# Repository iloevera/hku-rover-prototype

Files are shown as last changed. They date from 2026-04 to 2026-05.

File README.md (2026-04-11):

# HKU Martians Prototype Rover

Rudimentary all-in-one Power Distribution Board (PDB) and logic carrier designed for small 6-wheel rovers with a 4-DoF robotic arm.

Untitled design (4)

## 🚀 Key Specifications
- **Dimensions:** 97.0 x 77.4 mm
- **Power Input:** 6S LiPo (22.2V nominal, 25.2V max) via XT60.
- **Power Tree:**
  - **12V @ 30A:** High-current rail for BLDC/DC Main Drive motors. External module attached through XT30 connectors
  - **7.5V @ 5A:** Dedicated HV Servo rail (Optimized for 7.4V nominal servos). External module attached through XT30 connectors
  - **5.1V @ 5A:** On-board stabilized logic power for Pi 5 and peripherals. 3V3 Using Pico's built-in regulator.
- **Processing:**
  - Dual-core architecture: Raspberry Pi 5 (Thinking) + Pi Pico 2 (Doing).
  - High-speed UART communication bridge.
- **Actuation & Sensing:**
  - 6x PWM Encoder inputs.
  - 6x PWM-Controlled DC motor driver headers.
  - 4x High-Torque Servo ports with localized bulk capacitance.
  - Integrated 6S Battery Fuel Gauge (Voltage Divider + ADC).

## 🛠 Hardware Setup
### Battery Monitor Calibration
The internal voltage divider uses a **100kΩ (Top)** and **13.7kΩ (Bottom)** 1% precision resistor set. 
- **Max Input:** 25.2V
- **ADC Output:** ~3.03V
- **Safety Factor:** 10% headroom to prevent Pico ADC overvoltage.

### Communication
The Pi 5 and Pico 2 communicate via UART.
- **Baud Rate:** 115200 (Default)
- **Pinout:** Pi GPIO 14/15 <-> Pico GPIO 0/1.

## ⚠️ Assembly Warnings
1. **Thermal Reliefs:** High-current pads (XT60, Regulators, Motors) have thermal reliefs **DISABLED**. Use a high-power chisel-tip iron and pre-heat the board to 100°C for assembly.
2. **Capacitors:** Ensure C1 & C2 (2000uF) is rated for 50V minimum.
3. **USB Isolation:** Always use a USB isolator when debugging the Pi/Pico while the main battery is connected to prevent back-powering your PC.

## 📜 License
This project is released under GNU General Public License v3.0. Designed by **Ilo Japar / HKU ROVER Team**.

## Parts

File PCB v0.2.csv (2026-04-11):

Reference | Qty | Value | Taobao
C1,C2 | 2 | 1000u 50V (E) | https://item.taobao.com/item.htm?id=522579424493&skuId=4292850932858
C3,C4,C7 | 3 | 0.1u 50V 1206 (C) | https://item.taobao.com/item.htm?id=522554243102
C5 | 1 | 470u 50V (E) | https://item.taobao.com/item.htm?id=565000050337&skuId=4839680676732
C6,C8,C9,C10,C11 | 5 | 100u 50V (E) | https://item.taobao.com/item.htm?id=564996742055&skuId=5731925888317
D1 | 1 | 14.7V | https://item.taobao.com/item.htm?id=695101953366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
D2 | 1 | 3.3V | https://item.taobao.com/item.htm?id=697021351088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
D3 | 1 | SK1010C | https://item.taobao.com/item.htm?id=661190438436
D4 | 1 | SMAJ6.0A | https://item.taobao.com/item.htm?id=626801460817
D5,D6,D7,D8 | 4 | Green 0805 | https://item.taobao.com/item.htm?id=522554271548&skuId=5766142345201
F1 | 1 | 30A | https://item.taobao.com/item.htm?id=646550973988&upStreamPrice=131&skuId=5317343647485
F2 | 1 | 5A 1812 | https://detail.tmall.com/item.htm?id=680110340340&xxc=shop&skuId=5053061151671
F3 | 1 | 500mA 1206 | https://detail.tmall.com/item.htm?id=671048655631&skuId=4995581658123&xxc=shop
FB1,FB2,FB3 | 3 | BLM21PG220 | https://detail.tmall.com/item.htm?id=733934301476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
J1 | 1 | XT60-M | https://item.taobao.com/item.htm?from=cart&id=635227665423&skuId=4544457080563&upStreamPrice=247
J2 | 1 | Raspberry Pi 5 | https://item.taobao.com/item.htm?id=522576768218&skuId=3150252041904
J3,J5 | 2 | XT30-F | https://item.taobao.com/item.htm?from=cart&id=635227665423&skuId=4544457080563&upStreamPrice=247
J4,J6 | 2 | XT30-M | https://item.taobao.com/item.htm?from=cart&id=635227665423&skuId=4544457080563&upStreamPrice=247
J7,J8,J9,J10,J11,J12 | 6 | Screw 2.54mm 5P | https://item.taobao.com/item.htm?id=642057328277&skuId=4619071856328
J13,J14,J15,J16 | 4 | 2.54mm 3P | https://item.taobao.com/item.htm?id=522579376259&skuId=6139961763384
J17,J18,J19,J20,J21,J22 | 6 | JST-SH 3P | https://item.taobao.com/item.htm?id=616913039189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
Q1 | 1 | NCE1540KA | https://item.taobao.com/item.htm?id=809752933171
R1,R2 | 2 | 100k 0805 1% | https://item.taobao.com/item.htm?id=526088038633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
R3 | 1 | 13.3k 0805 1% | https://item.taobao.com/item.htm?id=526088038633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
R4,R5,R6,R7,R8 | 5 | 470R 0805 | https://item.taobao.com/item.htm?id=522573121620&skuId=5702455484812
U1 | 1 | 3.2~32V -> 5.1V 5A | https://item.taobao.com/item.htm?id=530479908999

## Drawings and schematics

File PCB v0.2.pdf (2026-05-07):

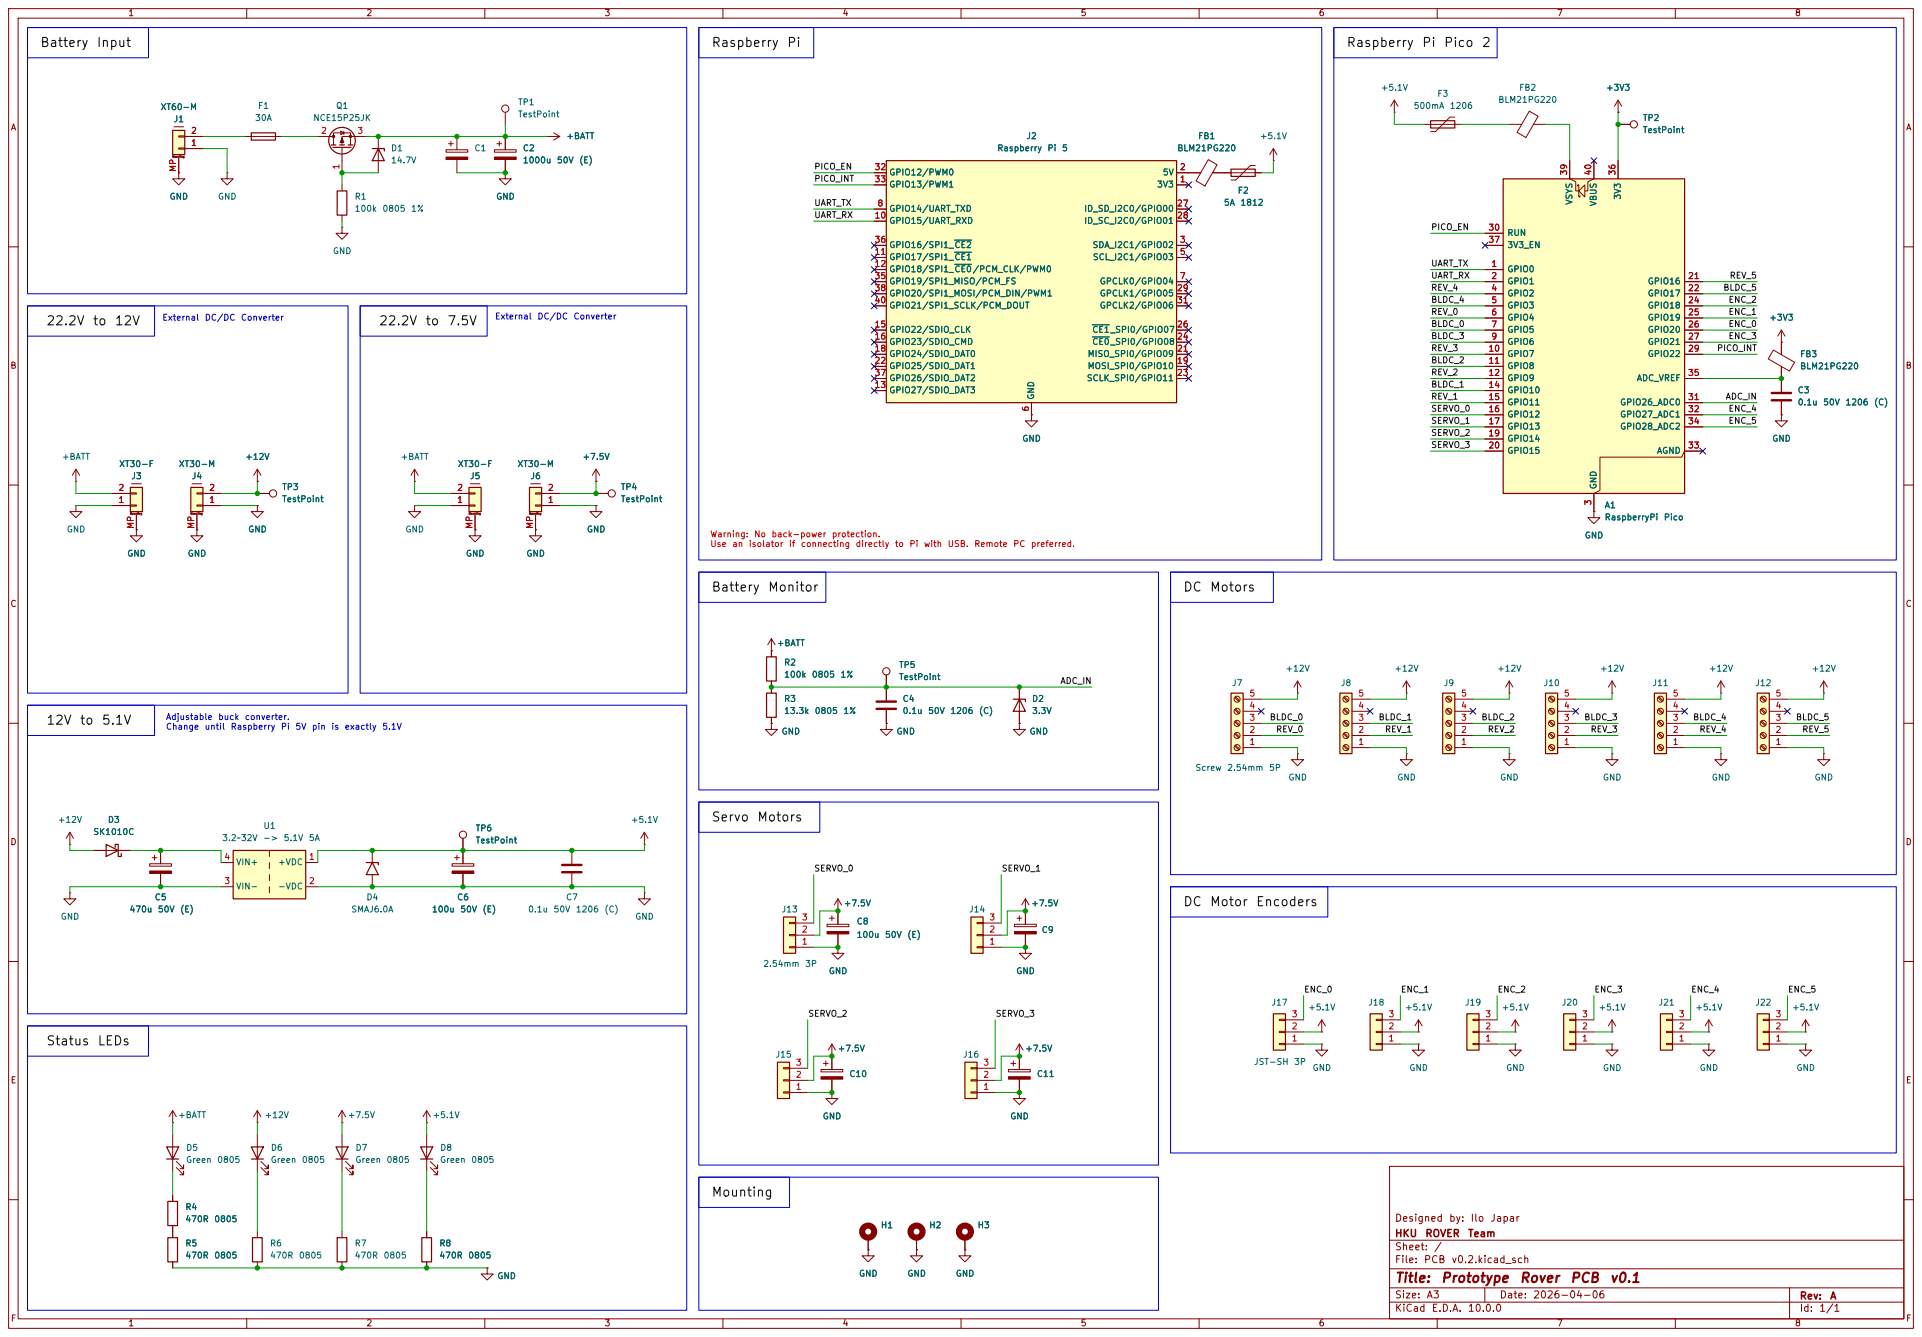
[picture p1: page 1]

+BATT
J2 Raspberry Pi 5 GND +7.5V GND

Use an isolator if connecting directly to Pi with USB. Remote PC preferred.

Adjustable buck converter.
Change until Raspberry Pi 5V pin is exactly 5.1V

Designed by: Ilo Japar
HKU ROVER Team
Sheet: /
File: PCB v0.2.kicad_sch
Title: Prototype Rover PCB v0.1

Size: A3 | Rev: A | F Date: 2026-04-06 KiCad E.D.A. 10.0.0

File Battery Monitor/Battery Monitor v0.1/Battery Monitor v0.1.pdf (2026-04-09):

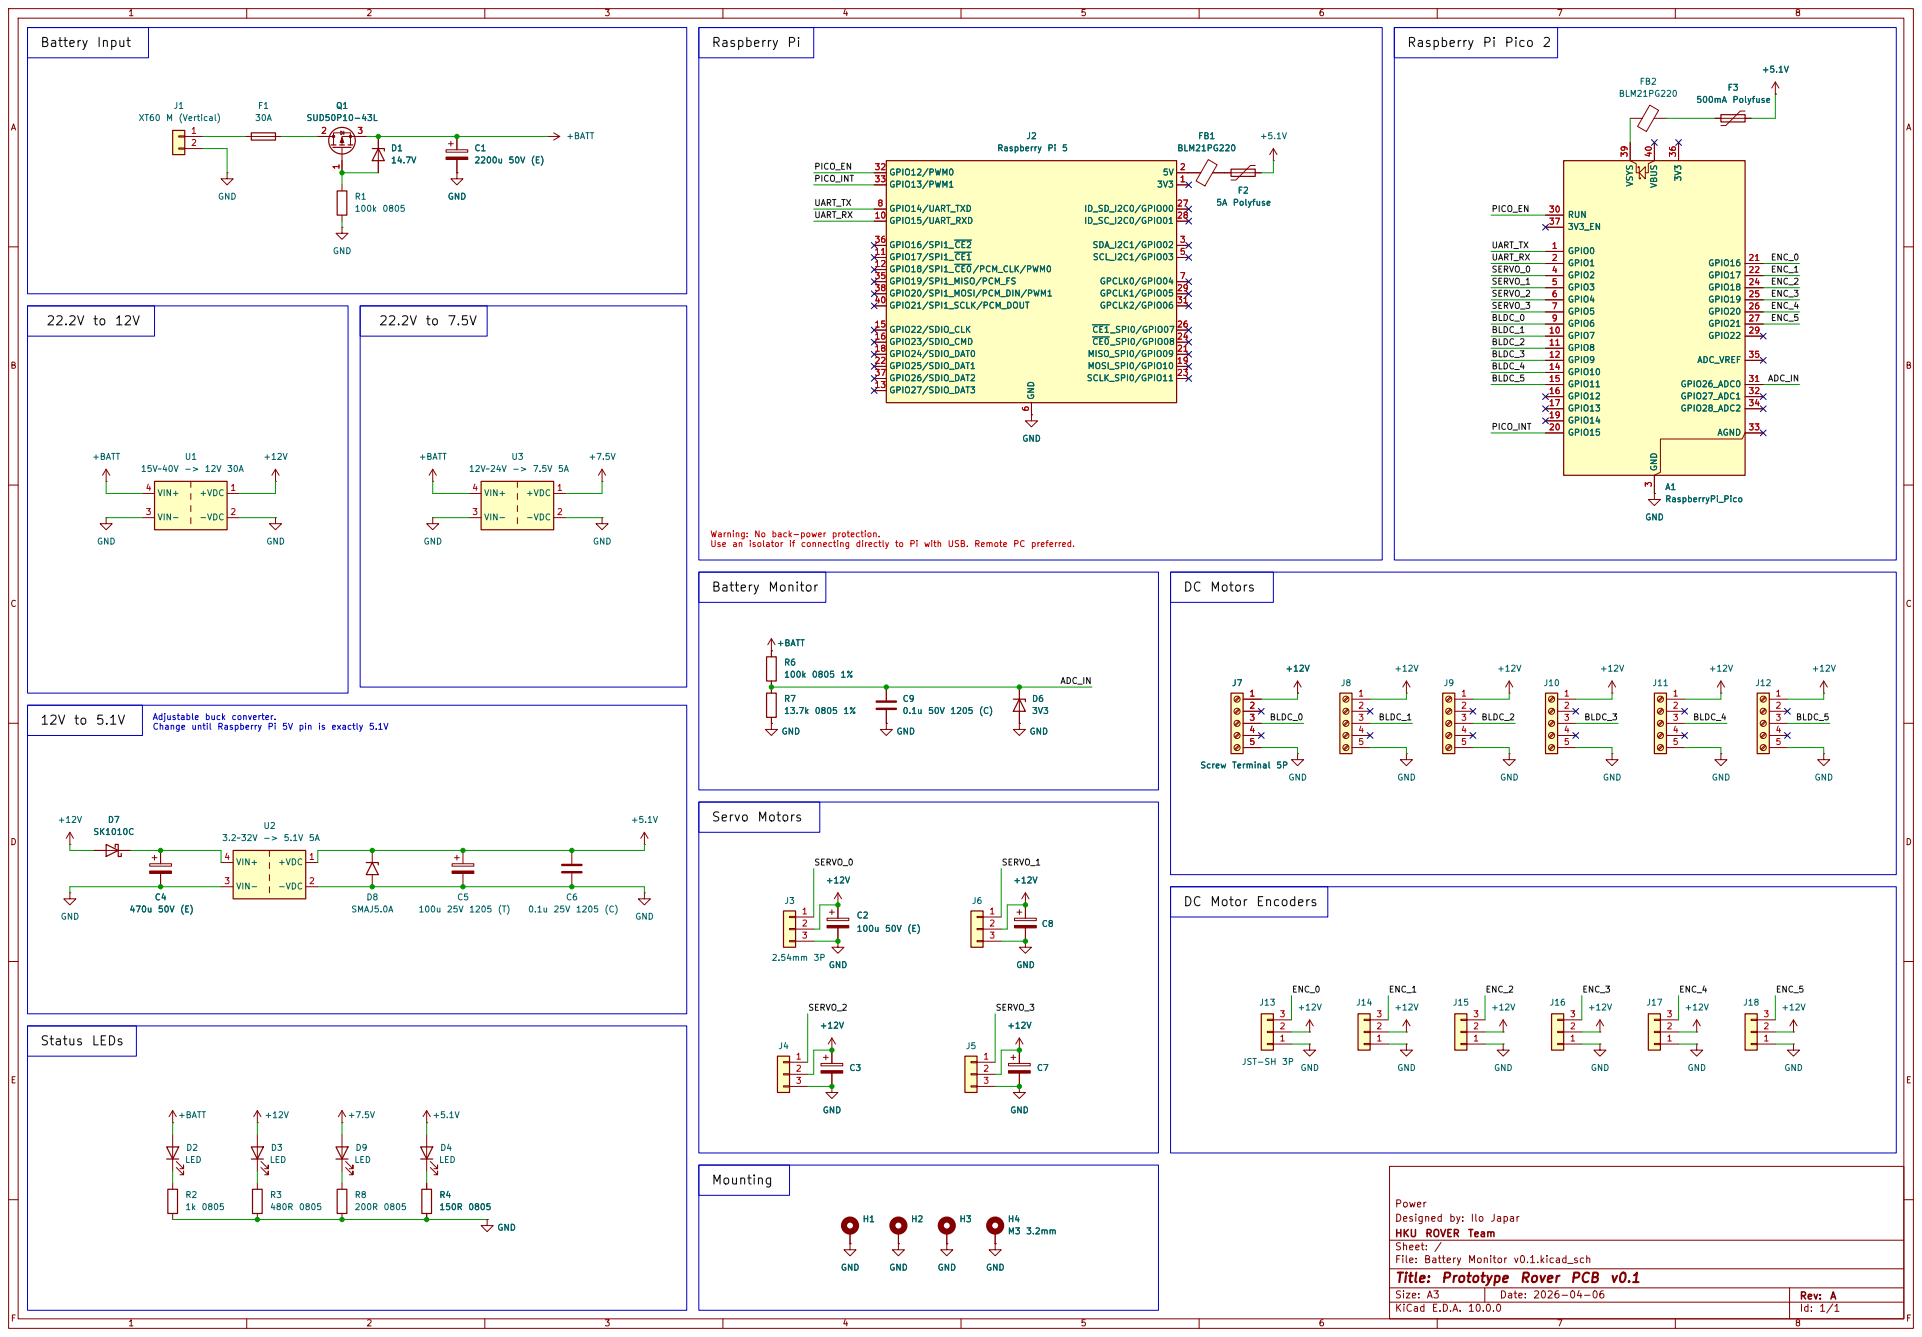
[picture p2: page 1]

Use an isolator if connecting directly to Pi with USB. Remote PC preferred. Q1

Designed by: Ilo Japar Power

HKU ROVER Team
Sheet: /
File: Battery Monitor v0.1.kicad_sch
Title: Prototype Rover PCB v0.1

Size: A3 | Rev: A | F Date: 2026-04-06 KiCad E.D.A. 10.0.0

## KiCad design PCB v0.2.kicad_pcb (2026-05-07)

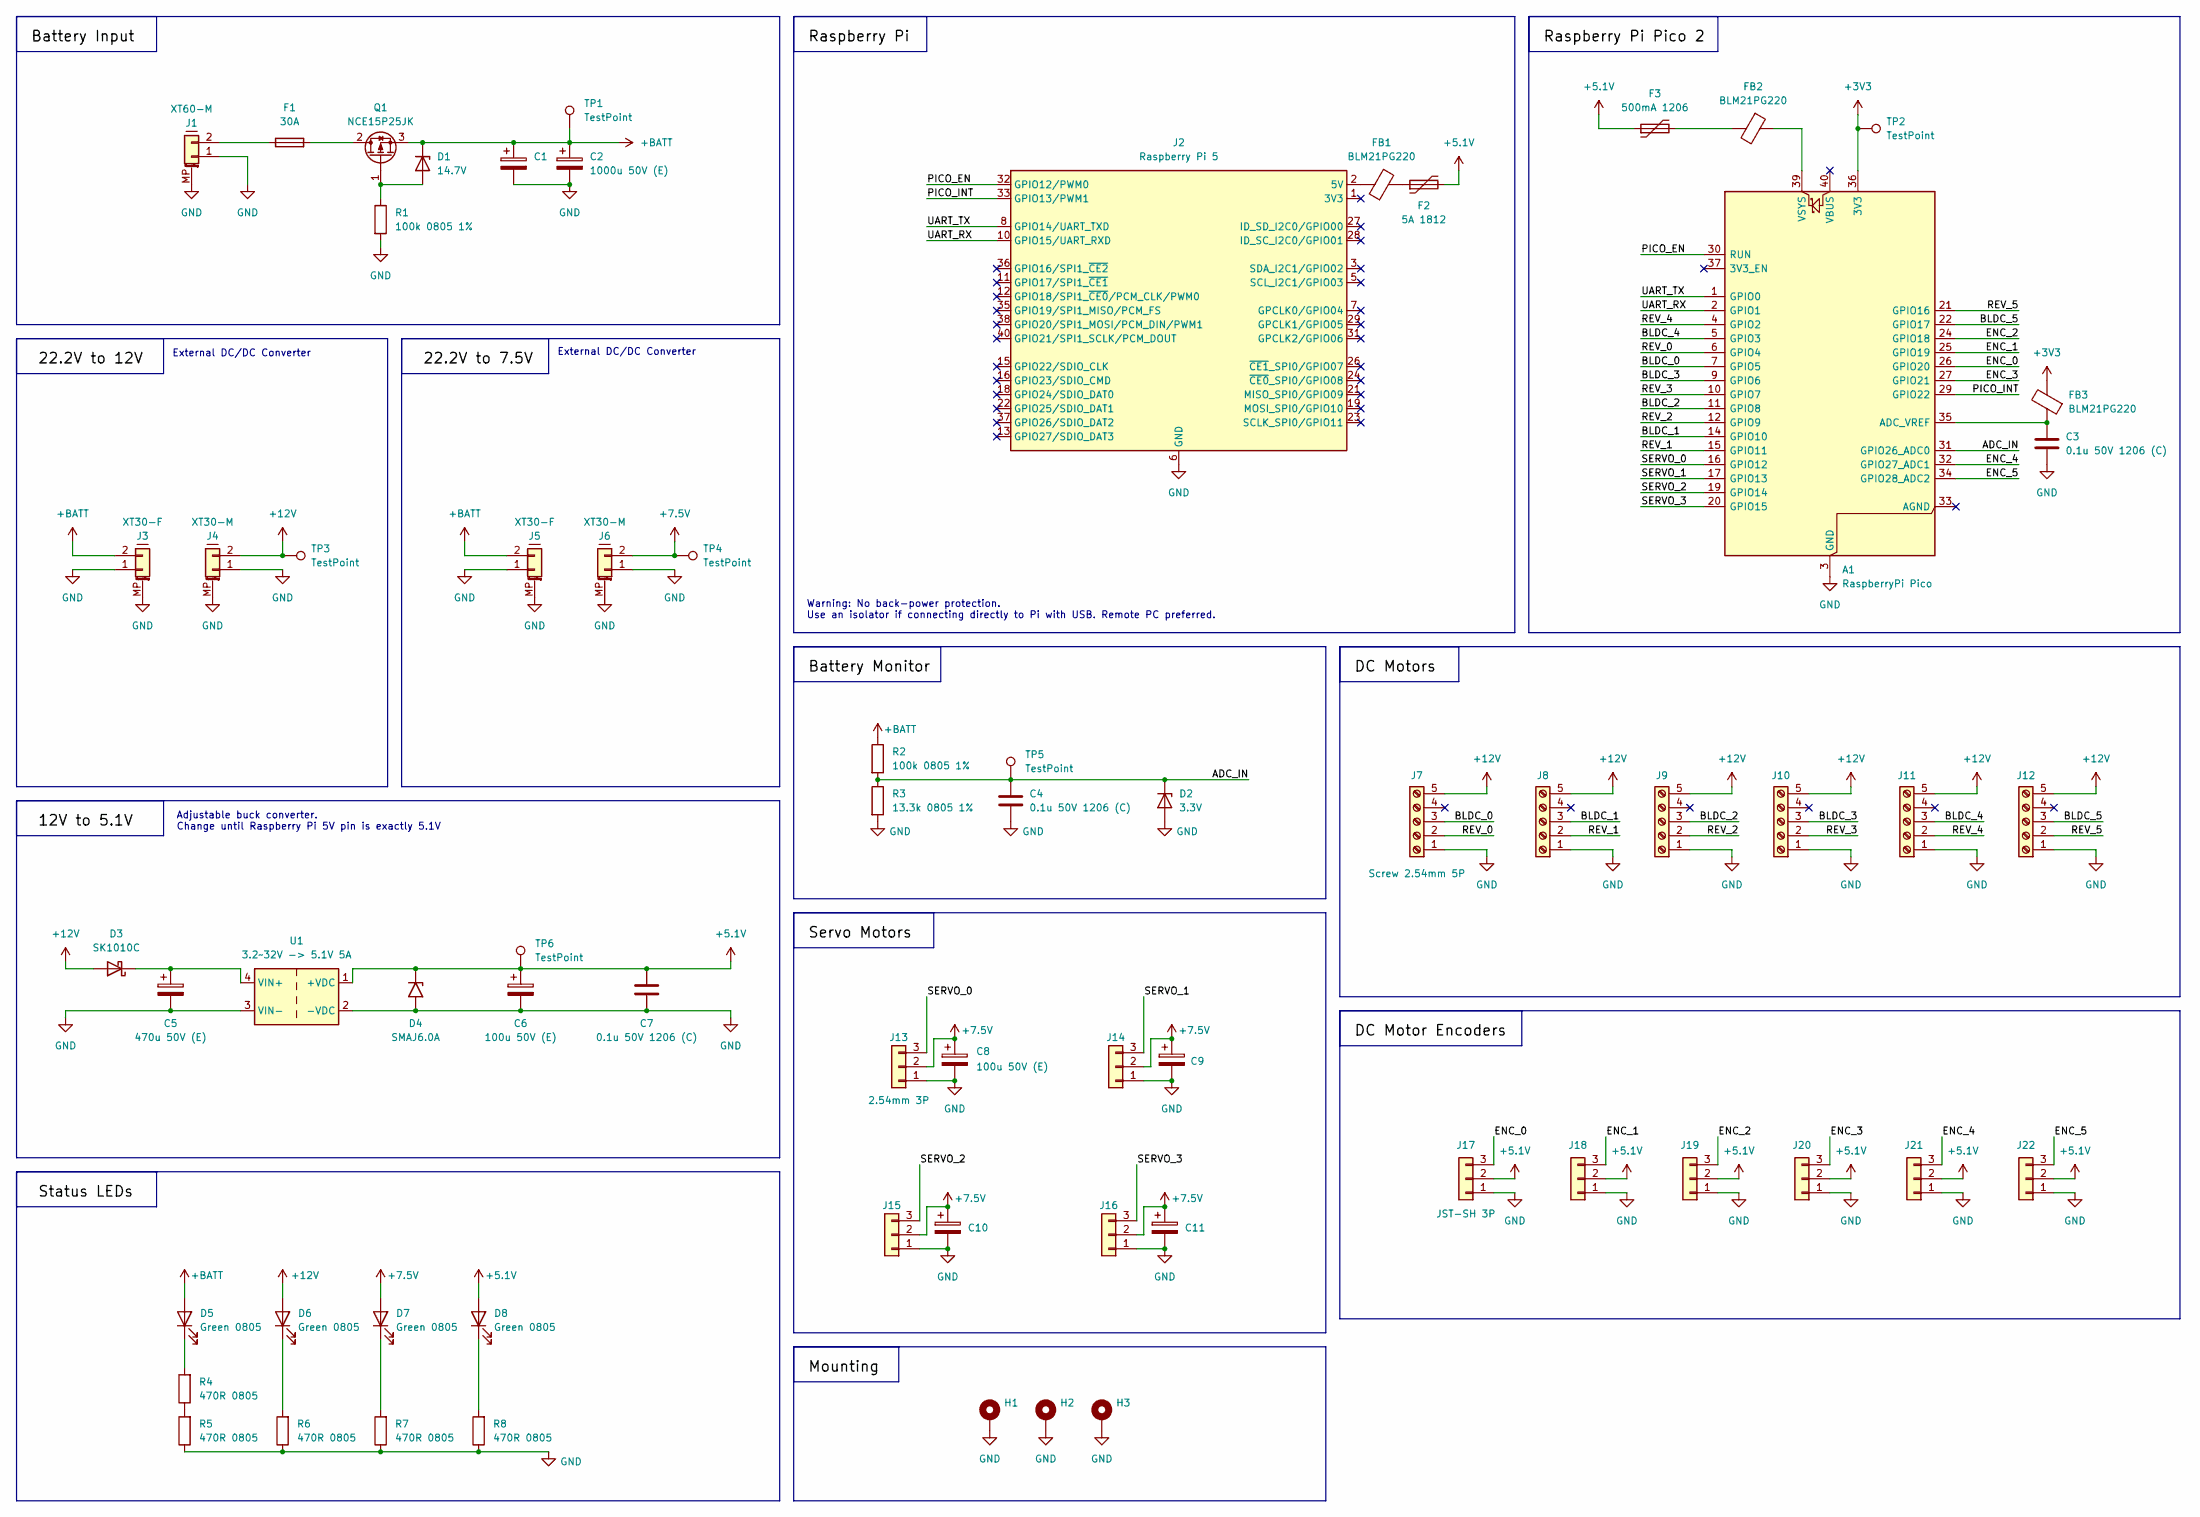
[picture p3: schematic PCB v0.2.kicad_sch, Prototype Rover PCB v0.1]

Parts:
A1: RaspberryPi Pico; RaspberryPi_Pico_SMD_HandSolder
C1, C2: 1000u 50V (E); CP_Radial_D13.0mm_P5.00mm
C3, C4, C7: 0.1u 50V 1206 (C); C_1206_3216Metric_Pad1.33x1.80mm_HandSolder
C5: 470u 50V (E); CP_Radial_D10.0mm_P5.00mm
C6, C8, C9, C10, C11: 100u 50V (E); CP_Radial_D8.0mm_P3.50mm
D1: 14.7V; Nexperia_CFP3_SOD-123W
D2: 3.3V; Nexperia_CFP3_SOD-123W
D3: SK1010C; D_SMC_Handsoldering
D4: SMAJ6.0A; D_SMA
D5, D6, D7, D8: Green 0805; LED_0805_2012Metric_Pad1.15x1.40mm_HandSolder
F1: 30A; FuseHolder_Blade_ATO_Littelfuse_FLR_178.6165
F2: 5A 1812; Fuse_1206_3216Metric
F3: 500mA 1206; Fuse_1206_3216Metric
FB1, FB2, FB3: BLM21PG220; L_0805_2012Metric_Pad1.05x1.20mm_HandSolder
H1, H2, H3: M3 3.2mm; MountingHole_3.2mm_M3_DIN965_Pad
J1: XT60-M; AMASS_XT60PW-M_1x02_P7.20mm_Horizontal
J2: Raspberry Pi 5; raspberrypi_2_3
J3, J5: XT30-F; AMASS_XT30PW-F_1x02_P2.50mm_Horizontal
J4, J6: XT30-M; AMASS_XT30PW-M_1x02_P2.50mm_Horizontal
J7, J8, J9, J10, J11, J12: Screw 2.54mm 5P; TerminalBlock_Xinya_XY308-2.54-5P_1x05_P2.54mm_Horizontal
J13, J14, J15, J16: 2.54mm 3P; PinHeader_1x03_P2.54mm_Vertical
J17, J18, J19, J20, J21, J22: JST-SH 3P; JST_SH_BM03B-SRSS-TB_1x03-1MP_P1.00mm_Vertical
Q1: NCE15P25JK; TO-252-2
R1, R2: 100k 0805 1%; R_0805_2012Metric_Pad1.20x1.40mm_HandSolder
R3: 13.3k 0805 1%; R_0805_2012Metric_Pad1.20x1.40mm_HandSolder
R4, R5, R6, R7, R8: 470R 0805; R_0805_2012Metric_Pad1.20x1.40mm_HandSolder
TP1, TP2, TP3, TP4, TP5, TP6: TestPoint; TestPoint_Pad_D1.5mm
U1: 3.2~32V -> 5.1V 5A; Buck_Converter_54x24mm

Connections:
+3V3: A1.36 (3V3), FB3.2, TP2.1 (1_1)
+5.1V: C6.1, C7.1, D4.1 (A1), D8.2 (A), F2.2, F3.1, J17.2, J18.2, J19.2, J20.2, J21.2, J22.2, TP6.1 (1_1), U1.1 (+VDC)
+7.5V: C8.1, C9.1, C10.1, C11.1, D7.2 (A), J6.2, J13.2, J14.2, J15.2, J16.2, TP4.1 (1_1)
+12V: D3.2 (A), D6.2 (A), J4.2, J7.5, J8.5, J9.5, J10.5, J11.5, J12.5, TP3.1 (1_1)
+BATT: C1.1, C2.1, D1.1 (K), D5.2 (A), J3.2, J5.2, Q1.3 (S), R2.1, TP1.1 (1_1)
/ADC_IN: A1.31 (GPIO26_ADC0), C4.1, D2.1 (K), R2.2, R3.1, TP5.1 (1_1)
/BLDC_0: A1.7 (GPIO5), J7.3
/BLDC_1: A1.14 (GPIO10), J8.3
/BLDC_2: A1.11 (GPIO8), J9.3
/BLDC_3: A1.9 (GPIO6), J10.3
/BLDC_4: A1.5 (GPIO3), J11.3
/BLDC_5: A1.22 (GPIO17), J12.3
/ENC_0: A1.26 (GPIO20), J17.3
/ENC_1: A1.25 (GPIO19), J18.3
/ENC_2: A1.24 (GPIO18), J19.3
/ENC_3: A1.27 (GPIO21), J20.3
/ENC_4: A1.32 (GPIO27_ADC1), J21.3
/ENC_5: A1.34 (GPIO28_ADC2), J22.3
/PICO_EN: A1.30 (RUN), J2.32 (GPIO12/PWM0)
/PICO_INT: A1.29 (GPIO22), J2.33 (GPIO13/PWM1)
/REV_0: A1.6 (GPIO4), J7.2
/REV_1: A1.15 (GPIO11), J8.2
/REV_2: A1.12 (GPIO9), J9.2
/REV_3: A1.10 (GPIO7), J10.2
/REV_4: A1.4 (GPIO2), J11.2
/REV_5: A1.21 (GPIO16), J12.2
/SERVO_0: A1.16 (GPIO12), J13.3
/SERVO_1: A1.17 (GPIO13), J14.3
/SERVO_2: A1.19 (GPIO14), J15.3
/SERVO_3: A1.20 (GPIO15), J16.3
/UART_RX: A1.2 (GPIO1), J2.10 (GPIO15/UART_RXD)
/UART_TX: A1.1 (GPIO0), J2.8 (GPIO14/UART_TXD)
GND: A1.3 (GND), A1.8 (GND), A1.13 (GND), A1.18 (GND), A1.23 (GND), A1.28 (GND), A1.38 (GND), C1.2, C2.2, C3.2, C4.2, C5.2, C6.2, C7.2, C8.2, C9.2, C10.2, C11.2, D2.2 (A), D4.2 (A2), H1.1 (1_1), H2.1 (1_1), H3.1 (1_1), J1.1, J1.MP (MountPin), J2.6 (GND), J2.9 (GND), J2.14 (GND), J2.20 (GND), J2.25 (GND), J2.30 (GND), J2.34 (GND), J2.39 (GND), J3.1, J3.MP (MountPin), J4.1, J4.MP (MountPin), J5.1, J5.MP (MountPin), J6.1, J6.MP (MountPin), J7.1, J8.1, J9.1, J10.1, J11.1, J12.1, J13.1, J14.1, J15.1, J16.1, J17.1, J18.1, J19.1, J20.1, J21.1, J22.1, R1.2, R3.2, R5.1, R6.1, R7.1, R8.1, U1.2 (-VDC), U1.3 (VIN-)
unnamed: A1.35 (ADC_VREF), C3.1, FB3.1
unnamed: A1.39 (VSYS), FB2.1
unnamed: D1.2 (A), Q1.1 (G), R1.1
unnamed: C5.1, D3.1 (K), U1.4 (VIN+)
unnamed: D5.1 (K), R4.2
unnamed: D6.1 (K), R6.2
unnamed: D7.1 (K), R7.2
unnamed: D8.1 (K), R8.2
unnamed: F2.1, FB1.2
unnamed: F3.2, FB2.2
unnamed: FB1.1, J2.2 (5V), J2.4 (5V)
unnamed: F1.1, J1.2
unnamed: F1.2, Q1.2 (D)
unnamed: R4.1, R5.2

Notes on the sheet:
Warning: No back-power protection. Use an isolator if connecting directly to Pi with USB. Remote PC preferred.
Adjustable buck converter. Change until Raspberry Pi 5V pin is exactly 5.1V
External DC/DC Converter

Board: 2 copper layers, 67 parts (1 on the bottom side), 47 nets, no tracks yet.

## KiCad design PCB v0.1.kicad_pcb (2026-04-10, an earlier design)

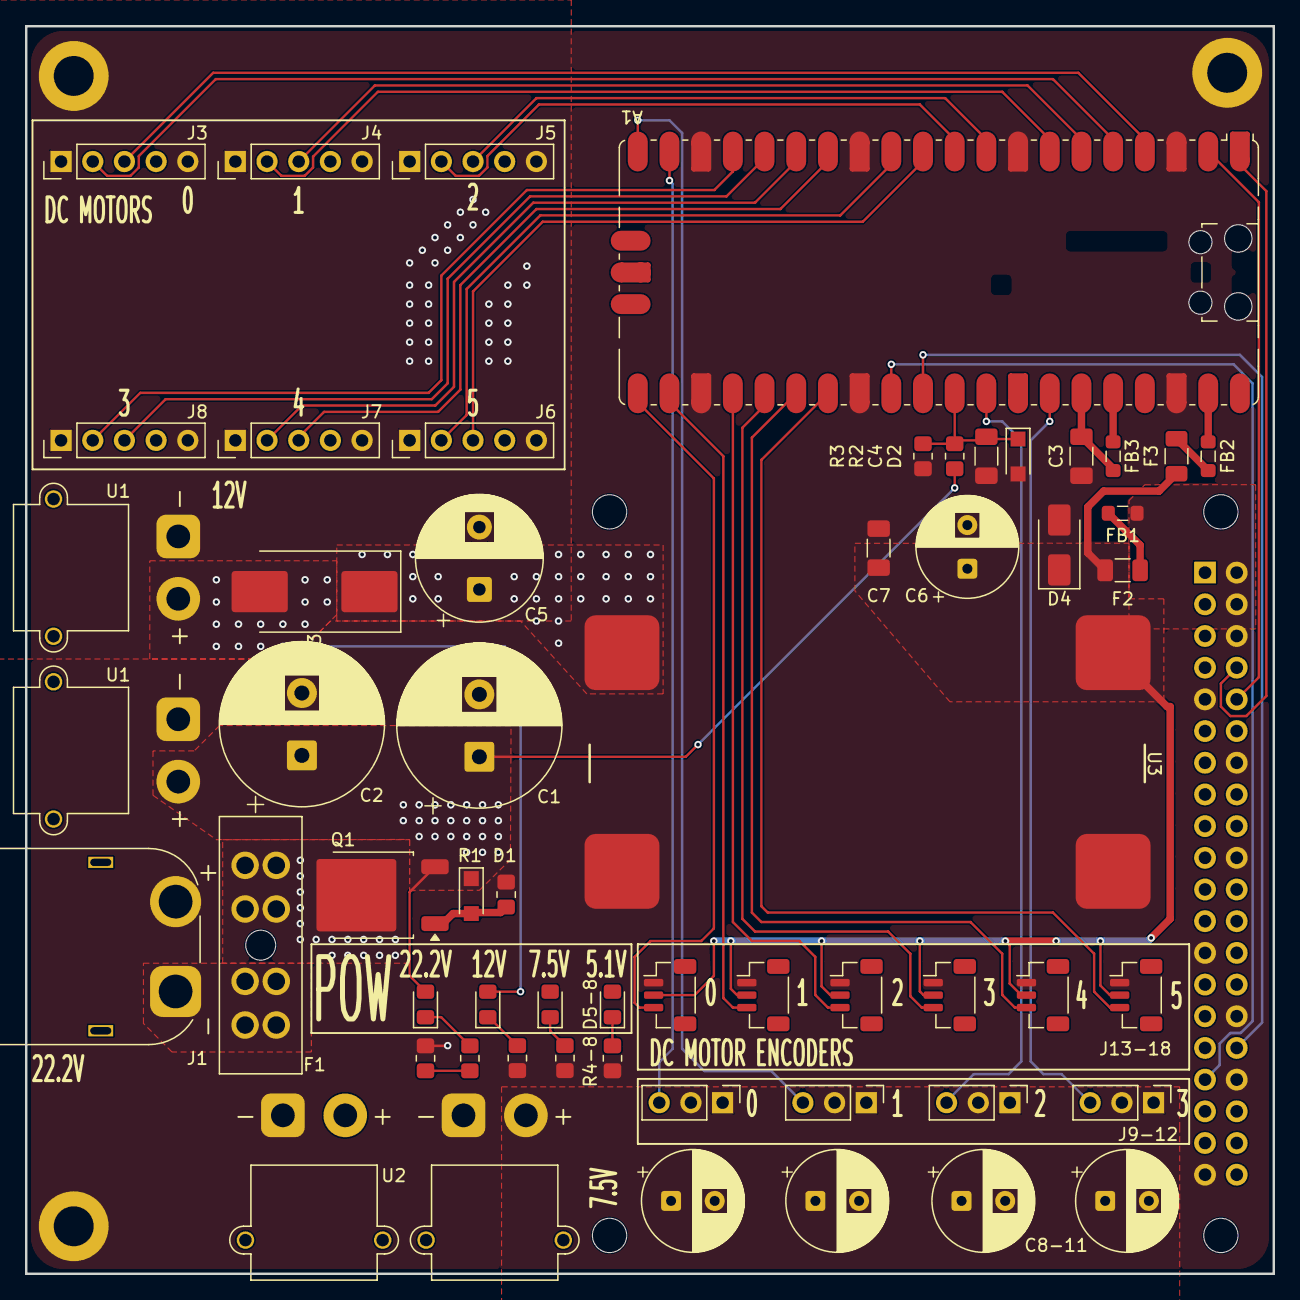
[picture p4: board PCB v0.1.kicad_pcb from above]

Board: 2 copper layers, 100.0 x 100.0 mm, 61 parts (0 on the bottom side), 47 nets.

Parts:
A1: RaspberryPi Pico; RaspberryPi_Pico_SMD_HandSolder
C1, C2: 1000u 50V (E); CP_Radial_D13.0mm_P5.00mm
C3, C4, C7: 0.1u 50V 1206 (C); C_1206_3216Metric_Pad1.33x1.80mm_HandSolder
C5: 470u 50V (E); CP_Radial_D10.0mm_P5.00mm
C6, C8, C9, C10, C11: 100u 50V (E); CP_Radial_D8.0mm_P3.50mm
D1: 14.7V; Nexperia_CFP3_SOD-123W
D2: 3.3V; Nexperia_CFP3_SOD-123W
D3: SK1010C; D_SMC_Handsoldering
D4: SMAJ6.0A; D_SMA
D5, D6, D7, D8: Green 0805; LED_0805_2012Metric_Pad1.15x1.40mm_HandSolder
F1: 30A; FuseHolder_Blade_ATO_Littelfuse_FLR_178.6165
F2: 5A 1812; Fuse_1206_3216Metric
F3: 500mA 1206; Fuse_1206_3216Metric
FB1, FB2, FB3: BLM21PG220; L_0805_2012Metric_Pad1.05x1.20mm_HandSolder
H1, H2, H3: M3 3.2mm; MountingHole_3.2mm_M3_DIN965_Pad
J1: XT60 M (Vertical); AMASS_XT60PW-M_1x02_P7.20mm_Horizontal
J2: Raspberry Pi 5; Raspberry_Pi_5
J3: Screw 2.54mm 5P; PinHeader_1x05_P2.54mm_Vertical
J4, J5, J6, J7, J8: Screw Terminal 5P; PinHeader_1x05_P2.54mm_Vertical
J9, J10, J11, J12: 2.54mm 3P; PinHeader_1x03_P2.54mm_Vertical
J13, J14, J15, J16, J17, J18: JST-SH 3P; JST_SH_BM03B-SRSS-TB_1x03-1MP_P1.00mm_Vertical
Q1: NCE1540KA; TO-252-2
R1, R2: 100k 0805 1%; R_0805_2012Metric_Pad1.20x1.40mm_HandSolder
R3: 13.3k 0805 1%; R_0805_2012Metric_Pad1.20x1.40mm_HandSolder
R4, R5, R6, R7, R8: 470R 0805; R_0805_2012Metric_Pad1.20x1.40mm_HandSolder
U1, U1#2, U2, U2#2: AMASS_XT30PW-M_1x02_P2.50mm_Horizontal
U3: 3.2~32V -> 5.1V 5A; Buck_Converter_44x22mm

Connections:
+3V3: A1.36 (3V3), FB3.2
+5.1V: C6.1, C7.1, D4.1 (A1), D8.2 (A), F2.2, F3.1, J13.2, J14.2, J15.2, J16.2, J17.2, J18.2, U3.1 (+VDC)
+7.5V: C8.1, C9.1, C10.1, C11.1, D7.2 (A), J9.2, J10.2, J11.2, J12.2, U2#2.1
+12V: D3.2 (A), D6.2 (A), J3.5, J4.5, J5.5, J6.5, J7.5, J8.5, U1#2.1
+BATT: C1.1, C2.1, D1.1 (K), D5.2 (A), Q1.3 (S), R2.1, U1.4, U2.4
/ADC_IN: A1.31 (GPIO26_ADC0), C4.1, D2.1 (K), R2.2, R3.1
/BLDC_0: A1.4 (GPIO2), J3.3
/BLDC_1: A1.6 (GPIO4), J4.3
/BLDC_2: A1.9 (GPIO6), J5.3
/BLDC_3: A1.11 (GPIO8), J6.3
/BLDC_4: A1.14 (GPIO10), J7.3
/BLDC_5: A1.16 (GPIO12), J8.3
/ENC_0: A1.21 (GPIO16), J13.3
/ENC_1: A1.22 (GPIO17), J14.3
/ENC_2: A1.24 (GPIO18), J15.3
/ENC_3: A1.25 (GPIO19), J16.3
/ENC_4: A1.26 (GPIO20), J17.3
/ENC_5: A1.27 (GPIO21), J18.3
/PICO_EN: A1.30 (RUN), J2.32 (GPIO12/PWM0)
/PICO_INT: A1.29 (GPIO22), J2.33 (GPIO13/PWM1)
/REV_0: A1.5 (GPIO3), J3.2
/REV_1: A1.7 (GPIO5), J4.2
/REV_2: A1.10 (GPIO7), J5.2
/REV_3: A1.12 (GPIO9), J6.2
/REV_4: A1.15 (GPIO11), J7.2
/REV_5: A1.17 (GPIO13), J8.2
/SERVO_0: A1.19 (GPIO14), J9.3
/SERVO_1: A1.20 (GPIO15), J10.3
/SERVO_2: A1.32 (GPIO27_ADC1), J11.3
/SERVO_3: A1.34 (GPIO28_ADC2), J12.3
/UART_RX: A1.2 (GPIO1), J2.10 (GPIO15/UART_RXD)
/UART_TX: A1.1 (GPIO0), J2.8 (GPIO14/UART_TXD)
GND: A1.3 (GND), A1.8 (GND), A1.13 (GND), A1.18 (GND), A1.23 (GND), A1.28 (GND), A1.38 (GND), C1.2, C2.2, C3.2, C4.2, C5.2, C6.2, C7.2, C8.2, C9.2, C10.2, C11.2, D2.2 (A), D4.2 (A2), H1.1 (1_1), H2.1 (1_1), H3.1 (1_1), J1.2, J2.6 (GND), J2.9 (GND), J2.14 (GND), J2.20 (GND), J2.25 (GND), J2.30 (GND), J2.34 (GND), J2.39 (GND), J3.1, J4.1, J5.1, J6.1, J7.1, J8.1, J9.1, J10.1, J11.1, J12.1, J13.1, J14.1, J15.1, J16.1, J17.1, J18.1, R1.2, R3.2, R5.1, R6.1, R7.1, R8.1, U1.3, U1#2.2, U2.3, U2#2.2, U3.2 (-VDC), U3.3 (VIN-)
unnamed: A1.35 (ADC_VREF), C3.1, FB3.1
unnamed: A1.39 (VSYS), FB2.1
unnamed: D1.2 (A), Q1.1 (G), R1.1
unnamed: C5.1, D3.1 (K), U3.4 (VIN+)
unnamed: D5.1 (K), R4.2
unnamed: D6.1 (K), R6.2
unnamed: D7.1 (K), R7.2
unnamed: D8.1 (K), R8.2
unnamed: F2.1, FB1.2
unnamed: F3.2, FB2.2
unnamed: FB1.1, J2.2 (5V), J2.4 (5V)
unnamed: F1.1, J1.1
unnamed: F1.2, Q1.2 (D)
unnamed: R4.1, R5.2

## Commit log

2026-04-07 WIP: Added power conversion & status LEDs
    [Battery Monitor v0.1.kicad_pcb, Battery Monitor v0.1.kicad_sch]
2026-04-08 Began implementation of motor control & battery monitor
    [Battery Monitor v0.1.kicad_sch]
2026-04-09 Finished schematic, added purchase links, began PCB layout
    [Battery Monitor v0.1 Control.kicad_sch, Battery Monitor v0.1.kicad_pcb, Battery Monitor v0.1.kicad_sch]
2026-04-10 Renamed project, began routing. Todo: Move servos up
    [Battery Monitor v0.1.kicad_pcb, Battery Monitor v0.1.kicad_sch, PCB v0.1.kicad_pcb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]
2026-04-10 Update .gitignore to remove BOM file exclusions and add PCB component list
    [PCB v0.1.csv]
2026-04-11 Renamed project to new version number
    [PCB v0.2-B_Cu.gbl, PCB v0.2-B_Mask.gbs, PCB v0.2-B_Paste.gbp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]
2026-04-11 Improved GND return path for BLDC motors
    [PCB v0.2-B_Cu.gbl, PCB v0.2-B_Mask.gbs, PCB v0.2-B_Paste.gbp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]
2026-04-11 Replaced DC/DC symbol in schematic with appropriate XT30 connectors, fixed XT60 polarity
    [PCB v0.2-B_Cu.gbl, PCB v0.2-B_Mask.gbs, PCB v0.2-B_Paste.gbp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]
2026-04-11 Change PCB image in README
    Updated image link in the README to a new design.
2026-05-07 Preparing for v0.3
    [PCB v0.2.kicad_pcb, PCB v0.2.kicad_sch]
